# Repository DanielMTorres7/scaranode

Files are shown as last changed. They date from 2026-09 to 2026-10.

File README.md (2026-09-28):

# ScaraNode

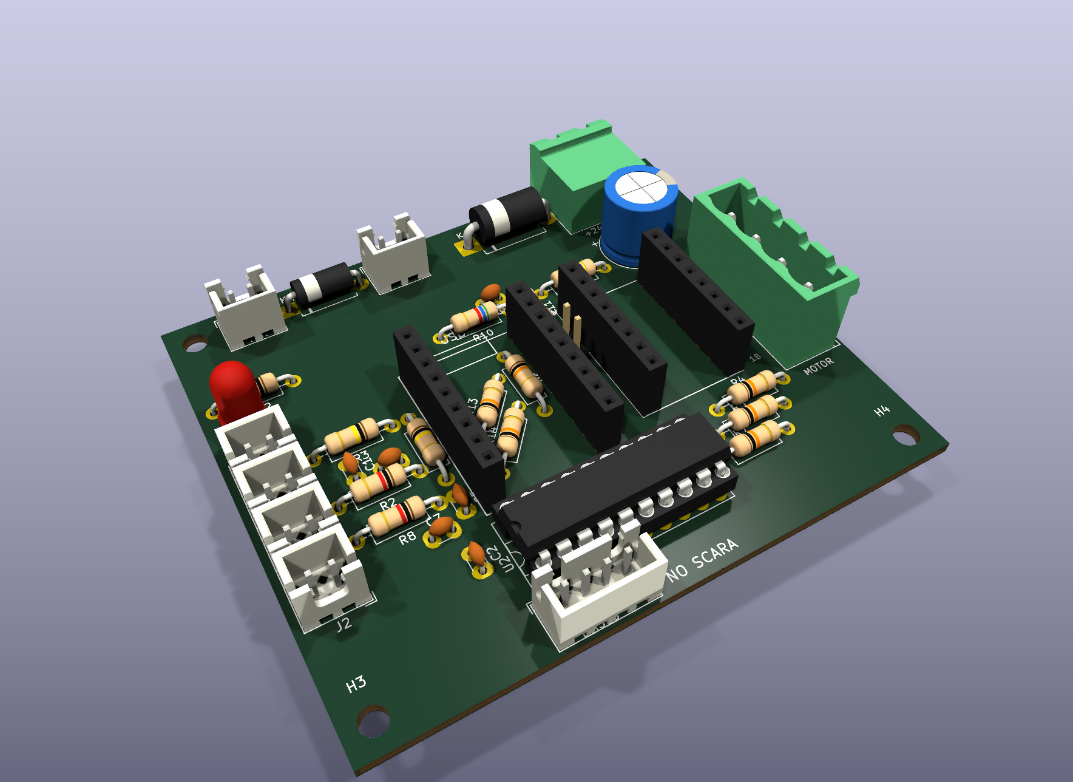
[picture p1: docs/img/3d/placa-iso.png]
ScaraNode


Placa de nó de motor **Klipper** para braço SCARA: **RP2040-Zero** + **TMC2209** (NEMA 17) e/ou driver
externo **DM556** (NEMA 23), cada um com STEP/DIR/enable próprios. Face única, 76 × 64 mm, feita para fresar em casa.

| Projetista | Revisão | Data | Estado |
|---|---|---|---|
| Daniel M. Torres | v18 | 27/09/2026 | Validada: 124 pinos, ERC e paridade 0, DRC de cobre sem erro, nenhuma curva de trilha de 90° |

📘 **[Manual completo](docs/README.md)** · 📄 **[PDF](docs/ScaraNode-Manual-v18.pdf)** ·
🧾 **[Lista de materiais](docs/02-lista-de-materiais.md)** · 🔧 **[Montagem](docs/04-montagem.md)** ·
⚙️ **[Klipper](docs/07-firmware-klipper.md)** ·
🎛️ **[Painel web](https://danielmtorres7.github.io/scaranode/)** ([como usar](firmware/painel/README.md))

## Estrutura

```
hardware/     placa e esquemático KiCad (ScaraNode.kicad_pro / .kicad_pcb / .kicad_sch + bibliotecas do projeto)
production/   arquivos para fabricar: gerber/, furação, BOM.csv
firmware/     configuração Klipper de referência; painel/ = painel web de bancada + firmware MicroPython
docs/         manual (Markdown + PDF), imagens, histórico de revisões
```

## Editar a placa

Abra `hardware/ScaraNode.kicad_pro` no **KiCad 10**: esquemático (`ScaraNode.kicad_sch`) e placa
(`ScaraNode.kicad_pcb`). As tabelas de biblioteca do projeto (`sym-lib-table`, `fp-lib-table`) apontam para as
bibliotecas padrão do KiCad 10 e para as próprias: `ScaraNode.kicad_sym` (RP2040-Zero, StepStick, 74ACT245, diodos)
e `ScaraNode.pretty` (soquetes do RP2040-Zero e do StepStick). Os comandos para
regerar Gerber e furação estão em [docs/03-fabricacao.md](docs/03-fabricacao.md#arquivos-de-produção).

Placa e esquemático foram gerados e conferidos por uma ferramenta própria em Python, que não faz parte deste
repositório (a paridade placa × esquemático é verificada pelo `kicad-cli`; a sincronização pela interface —
"Atualizar placa a partir do esquemático" — não foi testada). Os arquivos KiCad são completos e editáveis sem ela.

## Licença

Hardware sob **CERN-OHL-S-2.0** (ver [`LICENSE`](LICENSE)). Fotos de terceiros em `docs/img/componentes/`
mantêm as licenças listadas em [`CREDITOS.md`](docs/img/componentes/CREDITOS.md).

## Créditos

Modelos 3D das peças: bibliotecas oficiais do KiCad. Fotos de componentes: Wikimedia Commons, com
autores e licenças em [`docs/img/componentes/CREDITOS.md`](docs/img/componentes/CREDITOS.md).

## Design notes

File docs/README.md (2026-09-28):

# ScaraNode — Manual da Placa

<p align="center">ScaraNode em 3D</p>

Placa de nó de motor para um braço SCARA com **Klipper**: um **RP2040-Zero** por eixo, controlando um
**TMC2209** no soquete (NEMA 17) e/ou um **DM556** externo (NEMA 23), com canais independentes. Face única, feita para fresar em casa.

| | |
|---|---|
| **Projeto** | ScaraNode — nó de motor Klipper |
| **Projetista** | Daniel M. Torres |
| **Revisão** | v18 |
| **Data da revisão** | 27/09/2026 |
| **Placa** | 76 × 64 mm · FR-4 1,6 mm · cobre só na face de baixo (B.Cu) |
| **Ferramenta** | KiCad 10.0.6 · placa gerada por ferramenta própria em Python; fonte editável: `hardware/ScaraNode.kicad_pcb` |
| **Estado** | Validada: 124 pinos conferidos contra o esquemático (ERC 0, paridade 0), DRC de cobre sem erro, 0 ligações faltando e nenhuma curva de trilha de 90°; onde os courtyards se sobrepõem, corpos a ≥ 0,10 mm (menor 0,30 mm); vão mínimo 0,60 mm, anel mínimo 0,40 mm |

## Capítulos

| # | Capítulo | Conteúdo |
|---|---|---|
| 1 | [Visão geral](01-visao-geral.md) | O que a placa faz, especificações, blocos, diagrama |
| 2 | [Lista de materiais](02-lista-de-materiais.md) | Cada peça com foto, modelo 3D e onde encaixa |
| 3 | [Fabricação](03-fabricacao.md) | Regras de fresa, ferramentas, Gerber, espelhamento |
| 4 | [Montagem](04-montagem.md) | Ordem de solda passo a passo, polaridades, conferência |
| 5 | [Conectores, pinagem e jumpers](05-conectores-e-jumpers.md) | O que ligar em cada pino, jumper JU |
| 6 | [Circuitos e cálculos](06-circuitos.md) | Cada bloco explicado, com as contas |
| 7 | [Firmware Klipper](07-firmware-klipper.md) | Gravação do RP2040 e `printer.cfg` |
| 8 | [Primeira ligação e testes](08-testes.md) | Roteiro de ligação, diagnóstico, limites da placa |
| — | [Histórico de revisões](historico-de-revisoes.md) | Decisões de projeto, revisão por revisão |

**PDF:** [`ScaraNode-Manual-v18.pdf`](ScaraNode-Manual-v18.pdf), gerado destes mesmos arquivos. Esquemático: [`ScaraNode-Esquematico-v18.pdf`](ScaraNode-Esquematico-v18.pdf).

## Convenções deste manual

- **Vista de cima** = lado das peças, com o USB do RP2040-Zero para cima. Todas as imagens de montagem usam
  essa vista. A única vista espelhada é a do cobre, no capítulo de fabricação.
- Coordenadas em mm, com origem no canto superior esquerdo do RP2040-Zero (mesmo referencial da ferramenta de geração).
- Nomes de rede (`24V`, `VSENSE`, `STP`…) são os mesmos da placa no KiCad.
- ⚠️ marca o que queima peça ou inutiliza a placa se for feito errado.

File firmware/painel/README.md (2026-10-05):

# Painel web do ScaraNode

Painel de bancada para testar a placa sem Klipper: move o motor, configura o TMC2209 ou o DM556, lê fins de
curso, NTC e 24 V, e grava o próprio firmware na placa.

**Abrir:** <https://danielmtorres7.github.io/scaranode/> no **Chrome ou Edge** (computador). A página usa
Web Serial: a conexão vai direto do navegador para a placa ligada na USB do seu computador, sem passar
por servidor nenhum.

| Arquivo | O que é |
|---|---|
| `index.html` | o painel (arquivo único, sem dependências) |
| `no.py` | firmware MicroPython: servidor JSON pela USB, passos pela PIO + DMA |
| `main.py` | boot: deixa os drivers soltos e chama `no.rodar()` |
| `robo.html` | robô: várias placas ao mesmo tempo (J1, J2, Z), referência e desenho de SVG |

## Gravar o firmware

A placa precisa de **MicroPython** no RP2040-Zero (segure BOOT, ligue a USB e copie o `.uf2` do
[micropython.org](https://micropython.org/download/RPI_PICO/) para o drive `RPI-RP2`).
Depois, no painel, na aba **Firmware**:

1. confira a **revisão da placa** (só a v18): ela vai num `placa.py` (`REV = "v18"`) e decide os pinos;
2. clique em **Gravar firmware do site**.

O painel solta o motor, para o firmware e grava `main.py`, `no.py` e `placa.py` pelo raw REPL (como o
`mpremote`). Cada arquivo vai para um `.tmp`, é conferido (tamanho e SHA-256) e só então substitui o
antigo: se algo falhar no meio, a placa continua com o firmware anterior.

## Editar o firmware

Na aba **Firmware**, **Editar o firmware**: baixe `no.py`, `main.py` e `placa.py`, edite no seu editor e grave com
**Gravar arquivos do computador…** (um ou mais `.py`; só os escolhidos são trocados). Para voltar à versão
publicada, **Gravar firmware do site**. Para publicar a sua versão para todos, faça o commit aqui (veja abaixo).

## Pinos (v18)

| | v18 |
|---|---|
| STEP / DIR do TMC2209 | GP4 / GP5 |
| STEP / DIR do DM556 | GP6 / GP7 |
| UART do TMC2209 | GP2 |

As páginas não oferecem mais as placas até a v17 (STEP/DIR compartilhados, modo "Ambos"); o `no.py` ainda tem a pinagem delas.

Comuns: EN do TMC GP0, 24 V GP1, ENA do DM556 GP8, FIM1 GP27, FIM2 GP15, NTC GP29, LED GP16.
Revisão nova: uma linha na tabela `PLACAS` do `no.py` e uma opção no seletor do `index.html`.

## Robô (várias placas)

**Abrir:** <https://danielmtorres7.github.io/scaranode/robo.html> (ou o botão **Robô** no painel). Uma conexão
por placa: **Adicionar placa** para cada uma; na próxima vez o navegador reconecta sozinho.

- **Eixos:** cada eixo (J1, J2, Z) diz em que placa e em que driver está ligado, a redução (ou o avanço do fuso),
  o sentido, os limites, a velocidade e como é referenciado (manual ou por fim de curso). J1 e J2 precisam estar
  na mesma placa v18, um no TMC2209 e o outro no DM556: a placa entra no modo **dois**.
- **Tudo fica salvo na placa** (`config.json`, comando `salva`): driver, correntes, fins de curso e os eixos
  ligados nela; o comprimento do braço vai com o J1 e as alturas da caneta com o Z. A placa já liga
  configurada (motores soltos) e o painel lê tudo de volta ao conectar, em qualquer computador.
- **Firmware:** na aba **Placas**, cada placa mostra a versão dela e a do site; **Atualizar** grava a última
  versão com a revisão que a própria placa informa (v18). O `config.json` não é tocado.
- **Desenho:** formas prontas ou um arquivo SVG (linhas, curvas, retângulos, círculos; texto precisa virar
  curva), posição e tamanho na área de trabalho, velocidade. **Simular** mostra o movimento sem mexer nos
  motores; **Desenhar** manda a trajetória.

Como a trajetória anda: o painel faz a cinemática inversa e planeja a velocidade (reduz nos cantos e onde as
juntas ficariam rápidas demais), divide em segmentos de 10 ms e manda os passos de cada segmento para a placa
(`tjini`/`tj`). Na placa, cada canal tem a sua SM da PIO lendo um anel de 512 segmentos por DMA; as duas partem
no mesmo ciclo e o painel acerta os atrasos para os dois canais não se afastarem mais que ~1 µs. Se a USB
atrasar e os dados acabarem, a SM para no fim do que chegou e a posição continua exata.

O painel de uma placa troca o modo do driver para o que estiver escolhido nele: depois de usá-lo numa placa do
robô, reinicie a placa (ela volta ao que está no `config.json`).

## Publicar uma versão nova

Edite `no.py` (suba `FW = "painel 1.x"`) e dê push em `main`: o workflow `.github/workflows/painel.yml`
publica no GitHub Pages. Quem abrir o painel vê "diferente do site" ao conectar e grava com um clique.

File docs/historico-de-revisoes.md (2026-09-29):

# Histórico de revisões

Projetista: **Daniel M. Torres**.

| Rev. | Data | Resumo |
|---|---|---|
| v18 | 27/09/2026 | Um canal por driver: TMC2209 no GP4/GP5 e DM556 no GP6/GP7, independentes; UART do TMC2209 no pino 4 do soquete (GP2); sem o jumper ZM (MS1/MS2 fixos, endereço 3); segundo NTC (J8, GP26); segunda ventoinha (J9); conectores plugáveis 2EDG no J5/J6; furos M3 esquadrados; fusível de 2 A por placa na caixa central; nenhuma curva de trilha de 90° |
| v17 | 25/09/2026 | Esquemático KiCad publicado (ERC e paridade com a placa); 13 resistores iguais de 1/4 W; R13 e R14 inclinados a 50° com o GND do RP ligado direto ao plano; coluna da esquerda com folgas iguais; GND contínuo sem o jumper de fio JP1; faixas de cor nos renders |
| v16 | 25/09/2026 | Placa 76 × 64 mm com furos M3 alinhados + DXF mecânico; U2 em soquete DIP-20; borne do motor KF128 azul; NTC separado dos fins de curso; LED de 5 mm |
| v15 | 25/09/2026 | Conectores de sinal passam a JST XH 2,5 mm (as peças reais); 74ACT245 soldado direto; borne da 24 V verde e do motor azul |
| v14 | 25/09/2026 | ENA do DM556 no GP8 (J4 passa a 4 vias); pull-ups de 10k R13/R14 nos fins de curso. Manual e repositório publicados. |
| v13 | 25/09/2026 | Só duas brocas (1,0 e 1,6 mm) + M3 |
| v12 | 25/09/2026 | C10 = 470 µF 35 V; placa passa a 75,8 × 64 mm |
| v11 | 24/09/2026 | Jumper JU: UART do TMC2209 no GP5 |
| v10 | 24/09/2026 | LED D3 na borda; trilha de retorno de GND do borne |
| v9 | 24/09/2026 | Anel dos conectores KK corrigido (0,40 mm); primeiros Gerbers |
| v1–v8 | 24/09/2026 | Layout inicial, regras de fresa, pinagem do RP2040 |

## v18 — canais independentes, UART no pino 4 e trilhas sem curva de 90°

- **Um canal por driver.** Até a v17, o GP6/GP7 ia ao TMC2209 e ao 74ACT245 ao mesmo tempo: com os dois drivers
  ligados, os motores faziam o mesmo movimento. Agora cada driver tem STEP, DIR e enable próprios:

  | | STEP | DIR | Enable | UART |
  |---|---|---|---|---|
  | TMC2209 (soquete U4) | GP4 | GP5 | GP0 (ativo baixo) | GP2 (JU) |
  | DM556 (J4, via 74ACT245) | GP6 (`!`) | GP7 | GP8 (alto = habilitado) | — |

  Uma placa pode mover dois motores diferentes ao mesmo tempo. O DM556 fica com as trilhas da v17 até o 245. As do
  GP4/GP5 descem duas fileiras no canal entre o RP e o soquete do TMC.
- **UART no pino 4 do StepStick.** Nos módulos TMC2209 comuns (e no usado nos testes), o PDN_UART fica na
  posição do MS3 (pino 4), não no pino 5. O JU liga o GP2 ao pino 4, com o R7 (10k) como pull-up. O pino 5 fica
  livre. Módulos com a UART no pino 5 (Watterott SilentStepStick) deixam de servir.
- **Sem o jumper ZM.** Com a UART, o Klipper tira o micropasso do cfg (`mstep_reg_select`) e MS1/MS2 só dão o
  endereço; com um driver por RP, o endereço é fixo. R4 e R5 ficam: MS1 = MS2 = 1, endereço 3 (o mesmo do cfg) e
  1/16 em standalone. O jumper MS3 antigo, que aterraria a UART, sai junto.
  ⚠️ Placas até a v17: a UART vai ao pino 5. Com esse módulo, ligue um fio do JU.2 ao pino 4 e deixe o MS3 do ZM
  aberto.
- **Nenhuma curva de trilha de 90°.** Cada canto de 90° virou dois de 135°, com um trecho a 45° de 1 mm de perna.
  Junções em T continuam. A regra entrou na validação: a v17 tinha 18 cantos, a v18 tem 0.
- **Segundo NTC (J8, GP26).** Com dois motores na placa, cada um tem o seu termômetro. O pull-up (R15, 100k) fica
  deitado na vertical, ao lado do soquete do RP, do 3V3 ao GP26. O C1 e o C4 saíram dessa coluna e foram para o vão
  entre o R3 e o R2, e o C7 (100 nF) fica abaixo do R8. Os quatro conectores da esquerda (NTC1, FIM1, NTC2, FIM2)
  ficam a 6,05 mm uns dos outros, e a trilha de 5 V desceu 1,1 mm para o J2 caber. Com o GP26 ocupado, sobram GP3,
  GP14 e GP28: o ADXL345 (só SPI no Klipper) não cabe mais; use um acelerômetro I2C.
- **Fusível por placa, na caixa central.** Um TMC2209 pegou fogo a 1,7 A (acima dos 1,0–1,2 A que o StepStick
  aguenta), e o fusível único da máquina, dimensionado para tudo, não abriu. Agora cada placa tem o seu fusível de
  2 A, e cada DM556 o seu de 5 A, numa caixa de fusíveis de lâmina automotiva (32 V DC, fácil de achar). Ficou fora
  da placa: os DM556 também precisam de fusível e não passam por ela, e um porta-fusível de placa barato e fácil de
  achar não coube na faixa de 24 V com as duas brocas. Detalhes e contas no [capítulo 6](06-circuitos.md#fusíveis-fora-da-placa).
- **Segunda ventoinha (J9), sempre ligada**, entre o D2 e o D1: J7 no TMC2209, J9 no DM556 ou na caixa.
- **Conectores plugáveis 2EDG (5,08 mm)** no lugar dos bornes de parafuso: J5 (24 V) macho 90° 2EDGRC com o plugue
  entrando pela borda de cima; J6 (motor) macho vertical 2EDGVC, plugue por cima e fio para a direita. Plugue 2EDGK
  nos dois. O J6 desceu 1,6 mm (o macho é mais comprido e encostava no parafuso do H2).
- **Furos M3 esquadrados:** o H2 foi para o canto de cima (retângulo de 69 × 57 mm com os outros três). O J5 foi
  5,6 mm para a esquerda e o D1 4,5 mm; a 24 V passa a descer pelo R9 até o C10 e do C10 ao VM do TMC.
- Validado: 128 pinos, 0 violações de cobre, 0 ligações faltando, ERC e paridade 0.
- **Validada em hardware (29/09/2026)**, placa fresada na CNC, RP2040-Zero com MicroPython 1.29 e firmware do painel
  1.12: UART do TMC2209 pelo GP2 → pino 4 (endereço 3, versão 0x21), 24 V no GP1, NTC1 (GP29), NTC2 (GP26), FIM1 (GP27), FIM2 (GP15) e o canal do DM556
  (STEP GP6, DIR GP7, ENA GP8 pelo 74ACT245 até o J4) girando o motor. Na montagem, a perna 2 do 74ACT245 (saída
  PUL) sem contato deixava o DM556 só dar um tranco ao habilitar: confira as pernas do CI no soquete.

## v17 — esquemático e resistores iguais

- **Esquemático** em `hardware/ScaraNode.kicad_sch` e em [PDF](ScaraNode-Esquematico-v17.pdf): uma folha, blocos
  por função, rótulos na ponta dos pinos. ERC sem erro nem aviso; paridade placa × esquemático sem divergência.
  Símbolos próprios em `hardware/ScaraNode.kicad_sym`, footprints próprios em `hardware/ScaraNode.pretty`.
- Pinos livres ganham na placa a rede `unconnected-(…)` que o esquemático gera; o cobre não muda.
- **R13 e R14 passam a 1/4 W, furos a 10,16 mm** (antes 1/8 W a 7,62): os 13 resistores são iguais. Continuam
  embaixo do RP2040-Zero.
- Coluna da esquerda (XH, R2/R3/R8, C1/C4/C5, barra fêmea do RP) com folgas iguais entre corpos: ~0,9 mm do XH à
  perna do R e da perna do R ao capacitor (medidas com perna de 0,8 mm, acima da real), ~1,0 mm do capacitor à
  barra fêmea. O capacitor para no limite da isolação de 0,6 mm com as ilhas livres do RP.
- As exceções de courtyard deixam de ser uma lista fixa: onde os courtyards se sobrepõem ou os corpos ficam a menos
  de 2 mm, a folga real entre os corpos (desenho de fabricação, pernas pelo furo) tem que ser ≥ 0,10 mm. Menor
  folga: 0,30 mm (J7 × cabeça do M3 do H1). O DRC do KiCad continua marcando 13 sobreposições de courtyard como
  erro; são essas, conferidas pela folga real.
- **Sem jumper de fio**: o U2 (74ACT245), o C2 e a trilha de 5 V que chega a eles descem 1 mm; o J4 fica onde
  estava. O plano de GND passa a chegar à coluna da esquerda (NTC e fins de curso) entre o último pino do
  RP2040-Zero e a trilha de 5 V, e o JP1 (fio de GND por cima da trilha de 5 V) sai da placa, da lista de
  materiais e da montagem. O J4 fica a
  ~0,5 mm do soquete do U2; o U2 se afasta do RP (~1,7 mm).
- **R13 e R14 inclinados a 50°, paralelos**: a ilha do fim de curso fica na altura do GP27/GP15 (trilhas retas) e a
  ilha de 3V3 dos dois cai na mesma trilha de 3V3, que agora desce a ~9,4 mm da fileira esquerda do RP (antes
  descia a 3,2 mm). Com isso o **GND do RP2040-Zero liga direto ao plano de GND de cima** por um canal de
  ~6 mm. O R6 passa um pouco para a direita (1,3 mm) e o EN chega a ele em L, sem ilha de cobre solta a mais.
  Folgas: R13 × R14, R13 × R6 e R14 × R6 ~0,8 mm; R13/R14 a ~1,2 mm da barra fêmea; R6 a ~0,9 mm da barra da
  direita.
- Renders com as faixas de cor de cada resistor.
- Validado: 126 pinos, ERC 0, paridade 0, 0 violações de cobre, 0 ligações faltando. Furação: 118 × 1,0 ·
  8 × 1,6 · 4 × 3,2.

## v16 — dimensões redondas, soquete DIP e DXF

- Contorno passa de 75,8 × 64 para **76 × 64 mm** (borda direita +0,2 mm).
- Furos M3 a 3,5 mm das bordas: H1/H3/H4 num retângulo de 69 × 57 mm; H2 na coluna do H4, 18 mm abaixo da borda
  de cima. Antes: H1 e H3 desalinhados 0,2 mm, cotas quebradas.
- U2 com footprint de **soquete DIP-20** (mesmos furos, corpo maior). Exceção medida: o corpo do soquete termina
  a ~1 mm da perna do R7.
- `production/ScaraNode-mecanico.dxf`: contorno, furos e cotas.
- Coluna da esquerda reorganizada: **NTC (J3) sozinho em cima** e os **dois fins de curso (J1, J2) juntos**
  mais abaixo, com um vão de ~9 mm entre os grupos. O J2 fica no limite da trilha de 5 V (y = 41,2).
- **LED de 5 mm** (mesmo passo de 2,54 mm e furo de 1,0 mm do de 3 mm); o R12 subiu 1 mm para ele caber.
  Folgas medidas: LED a ~0,7 mm do J3; J1 a ~1,6 mm da perna do R8.
- Validado: 128 pinos, 0 violações de cobre, 0 ligações faltando.

## v15 — conectores JST XH

- J1, J2, J3, J4 e J7 trocam o footprint Molex KK (2,54 mm) pelo **JST XH** (B2B/B4B-XH-A, 2,5 mm), que é o
  conector usado de fato. As ilhas continuam ovais de 1,8 × 2,4 mm com furo de 1,0 mm.
- J4: as trilhas do 74ACT245 (passo 2,54) fazem um desvio curto até os pinos do XH (passo 2,5).
- O corpo do XH é mais largo que o do KK. Exceções de courtyard aceitas, com as medidas do F.Fab:
  J1/J2/J3 × R2/R3/R8 (plástico a ~0,2 mm da perna do resistor, sem cobre no meio) e J7 × H1/D2 (~1 mm da
  cabeça do M3, ~1,5 mm da perna do D2). Afastar a coluna para a esquerda violaria a isolação da trilha de 5 V.
- U2 soldado direto (sem soquete DIP). Borne J5 verde (24 V), J6 azul (motor).
- Validado: 128 pinos, 0 violações de cobre, 0 ligações faltando. Furação igual: 120 × 1,0 · 8 × 1,6 · 4 × 3,2.

## v14 — ENA do DM556 e pull-ups dos fins de curso

- **ENA:** GP8 → B3 do 74ACT245 (pino 16, antes em GND) → A3 (pino 4) → J4.4. O J4 passa a KF2510 de
  4 vias: 5V, PUL−, DIR−, ENA−, com o ENA+ do DM556 no 5 V como PUL+/DIR+. GP8 alto = motor habilitado
  (`enable_pin: gpio8`, sem `!`). Com o RP em reset ou em boot, o GP8 fica baixo e o DM556 fica
  desabilitado até o Klipper assumir.
- **Pull-ups de 10k** R13 (GP27/FIM1) e R14 (GP15/FIM2) do lado do RP, embaixo do módulo. São de 1/8 W
  (DIN0204, furos a 7,62 mm), porque o de 1/4 W encostava no soquete. O R14 fica inclinado 60°.
- Exceção de DRC aceita: o canto do courtyard do R14 invade ~0,2 mm o do soquete do RP. A ilha fica a
  0,68 mm do plástico.
- Validado: 128 pinos, 0 violações de cobre, 0 ligações faltando.

## v13 — só duas brocas

- Furos ≤ 1,2 mm viram 1,0 mm; entre 1,2 e 3,0 mm viram 1,6 mm; 3,2 mm (M3) fica. As ilhas cresceram onde
  foi preciso para manter o anel ≥ 0,4 mm.
- Pinos 1 e 19 do U2 com ligação sólida ao plano (não cabia o alívio térmico).

## v12 — C10 de 470 µF

- C10 = 470 µF 35 V (Ø10 mm, passo 5 mm), para absorver a energia de frenagem com o D1 em série.
  Com 470 µF, o VM sobe a ~27,4 V na frenagem estimada; com 100 µF chegava a ~30 V.
- A faixa de 24 V inteira subiu 4 mm para o capacitor caber; a placa passou a 75,8 × 64 mm.

## v11 — jumper de UART

- JU (1x2) entre o RP e o TMC: JU.2 ← GP5, JU.1 → pino 5 do StepStick (PDN_UART). Aberto = standalone.
- Sem resistor e sem pull-up: UART de 1 fio half-duplex.
- Os pinos 5–6 do soquete não ficam mais livres para o curto RST/SLP de A4988/DRV8825.

## v10 — LED na borda e retorno de GND

- D3 na borda esquerda, abaixo do R12.
- Trilha de GND de 2,5 mm do borne J5 até o C10 e dali ao pino 15 do TMC: caminho sólido para os pulsos do
  chopper, sem depender dos raios do alívio térmico.

## v9 — pronta para fresar

- Conectores KK com ilha oval de 1,8 × 2,4 mm e furo de 1,0 mm (anel de 0,40 mm; a biblioteca deixava
  0,28 mm).
- Menor vão entre redes: 0,601 mm. Menor anel: 0,40 mm.
- Primeiros Gerbers e a regra de espelhamento para fresar com o cobre para cima.

## Decisões de projeto que valem para todas as revisões

- **Fresa desconhecida → regras seguras:** isolação de 0,6 mm, sinal de 1,2 mm, ilhas generosas.
- **Ilhas de cobre soltas são mantidas:** sobra menos cobre para a fresa tirar.
- **Sem entrada de 5 V:** o USB é obrigatório para o Klipper e já alimenta a lógica.
- **Pino 6 (CLK) do StepStick livre:** aterrar sem medir o módulo pode danificar variantes que usam esse
  pino para outra coisa.
- **Sem homing sensorless:** o módulo usado não expõe o DIAG; o homing é por chave (J1/J2).
- **Fusível da 24 V:** fora da placa, na caixa central, mas **um por placa** (2 A) e um por DM556 (5 A) desde a v18.
- **LED:** R12 = 10k (~2,2 mA). Para mais brilho, R12 = 4k7 (~4,6 mA).

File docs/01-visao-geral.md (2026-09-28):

# 1. Visão geral

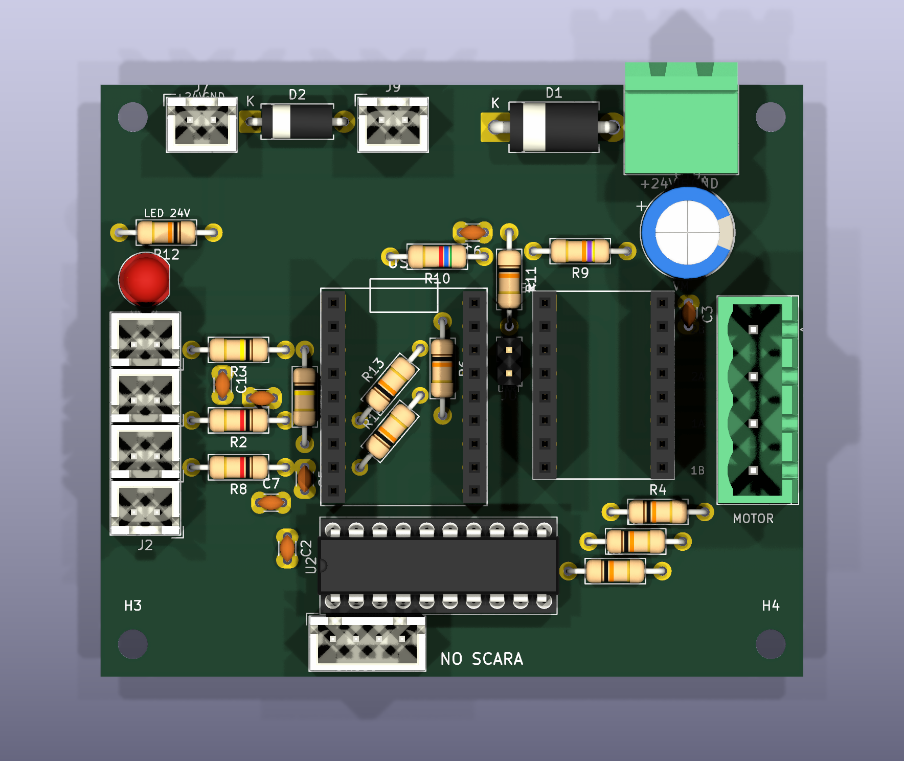
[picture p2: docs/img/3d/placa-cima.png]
Vista de cima em 3D


## O que a placa faz

Cada nó controla **um motor** do SCARA. O RP2040-Zero roda o firmware do Klipper e conversa com o host
(Raspberry Pi ou PC) pelo USB. O host coordena os quatro nós:

| Nó | Junta | Motor | Driver |
|---|---|---|---|
| J1 | ombro | NEMA 23 | DM556 externo, pelo conector J4 |
| J2 | cotovelo | NEMA 17 | TMC2209 no soquete U4 |
| Z | vertical | NEMA 23 | DM556 externo, pelo conector J4 |
| J3 | rotação da ferramenta | NEMA 17 | TMC2209 no soquete U4 |

É a **mesma placa nos quatro nós**. Só muda o que se monta nela:

| Variante | Monta | Fica vazio |
|---|---|---|
| **TMC2209** (J2, J3) | tudo, inclusive C3, R4–R7, JU, J6 e o módulo TMC2209 | J4 pode ficar sem cabo (o 74ACT245 não atrapalha) |
| **DM556** (J1, Z) | tudo menos o módulo TMC2209 | soquete U4 e conector J6 vazios; R4–R7 e JU opcionais |

## Especificações

| Item | Valor |
|---|---|
| Dimensões | 76 × 64 mm, 4 furos M3 (Ø3,2) a 3,5 mm das bordas; [desenho mecânico](03-fabricacao.md#desenho-mecânico) |
| Material | FR-4 1,6 mm, cobre só embaixo (B.Cu), fresada |
| Alimentação de potência | 24 V no conector plugável J5 (protegida contra inversão e surto) |
| Alimentação da lógica | 5 V e 3,3 V do USB do RP2040-Zero (ver [por que não há entrada 5 V](08-testes.md#o-que-a-placa-não-faz)) |
| Controle | Klipper, um RP2040-Zero por nó, USB para o host; até dois motores por nó (um no TMC2209, outro no DM556) |
| Driver interno | TMC2209 StepStick: 1,0–1,2 A RMS na prática |
| Driver externo | DM556 (ou similar, opto de ânodo comum): PUL, DIR e ENA em 5 V |
| Entradas | 2 NTC (um por motor), 2 fins de curso, monitor da 24 V |
| Saídas | motor (4 fios), ventoinha 24 V, PUL/DIR/ENA para driver externo, LED de 24 V |

## Diagrama de blocos

```mermaid
flowchart TB
    HOST["Host Klipper<br/>(Pi / PC)"] -- USB --> RP["U1 RP2040-Zero"]
    PSU["Fonte 24 V"] --> FUS["caixa de fusíveis<br/>2 A por placa"] --> J5["J5 conector 24 V"] --> D1["D1 1N5822<br/>anti-inversão"] --> BUS(("24 V"))
    BUS --> TVS["D2 P6KE30A + C10 470 µF"]
    BUS --> FAN["J7 ventoinha"]
    BUS --> LED["D3 LED + R12"]
    BUS --> DIV["R9/R10 divisor"] -- "VSENSE GP1" --> RP
    BUS -- VMOT --> TMC["U4 TMC2209"]
    RP -- "EN GP0 · STEP GP4 · DIR GP5" --> TMC
    RP -. "UART GP2 (JU)" .-> TMC
    TMC --> J6["J6 motor NEMA 17"]
    RP -- "STEP GP6 · DIR GP7 · ENA GP8" --> BUF["U2 74ACT245<br/>3,3 → 5 V"] --> J4["J4 → DM556"]
    NTC["J3 NTC1 · J8 NTC2"] -- "GP29 · GP26" --> RP
    SW["J1 / J2 fins de curso"] -- "GP27 · GP15" --> RP
```

## Blocos e peças

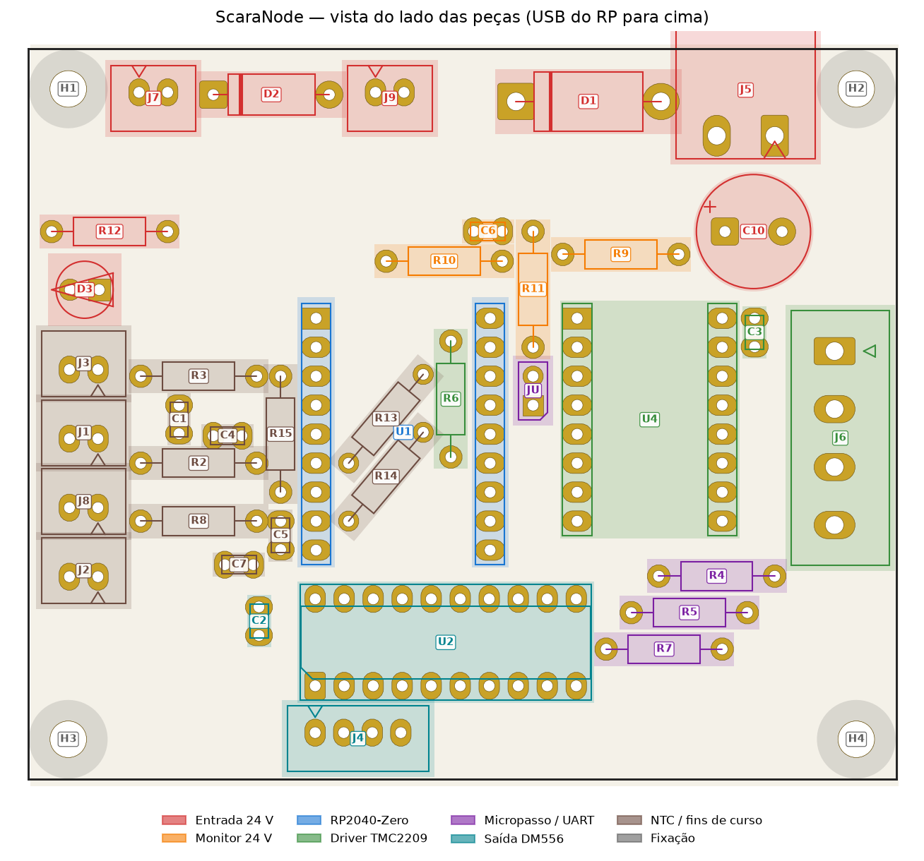
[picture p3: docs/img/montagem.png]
Peças coloridas por bloco


| Bloco | Peças | Função |
|---|---|---|
| Entrada 24 V | J5, D1, C10, D2, D3, R12, J7, J9 | Recebe a 24 V (fusível de 2 A por placa na caixa central). D1 protege contra inversão, D2 (TVS) contra surto, C10 guarda a energia de frenagem do motor, D3 acende com 24 V, J7 alimenta a ventoinha. |
| Monitor de 24 V | R9, R10, C6, R11 | Divisor 47k/5k6 leva 24 V a ~2,5 V no GP1. Se a potência cair, o Klipper faz M112. |
| Cérebro | U1 RP2040-Zero | Gera STEP/DIR, lê os sensores, fala com o host por USB. Fornece o 5 V (do USB) e o 3,3 V (regulador do módulo). |
| Driver TMC2209 | U4, R6, C3, J6 | Módulo StepStick. R6 deixa o driver desligado até o Klipper assumir. C3 desacopla o VMOT. J6 é o conector do motor. |
| Micropasso / UART | R4, R5, R7, JU | Pull-ups de 10k fixos em MS1/MS2 (R4, R5): endereço UART 3, ou 1/16 em standalone. JU fechado liga o GP2 ao PDN_UART (pino 4), que tem o R7 de pull-up. |
| Saída DM556 | U2, C2, J4 | Buffer de 3,3 para 5 V. As saídas afundam PUL−, DIR− e ENA− do DM556 (ânodo comum no 5 V). |
| NTC e fins de curso | J1, J2, J3, J8, R2, R3, R8, R13, R14, R15, C1, C4, C5, C7 | Dois NTC com pull-up de 100k no ADC. Chaves para GND com pull-up de 10k e filtro RC. |

Detalhes e contas no capítulo [6. Circuitos](06-circuitos.md).

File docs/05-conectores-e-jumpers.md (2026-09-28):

# 5. Conectores, pinagem e jumpers

Todas as posições abaixo são na **vista de cima** (lado das peças, USB do RP para cima).

## Pinagem do RP2040-Zero

Coluna esquerda, de cima para baixo: `5V, GND, 3V3, GP29, GP28, GP27, GP26, GP15, GP14`.
Coluna direita, de cima para baixo: `GP0 … GP8`. Os pinos castelados de baixo (GP9–GP13) não são usados.

| Pino | Rede | Função | No `printer.cfg` |
|---|---|---|---|
| 5V | `5V` | Vem do USB; alimenta o 74ACT245 e o PUL+/DIR+/ENA+ do DM556 | — |
| GND | `GND` | Terra comum (USB, 24 V, sensores) | — |
| 3V3 | `3V3` | Regulador do módulo; alimenta o VDD do TMC, os pull-ups e o NTC | — |
| GP0 | `EN` | Enable do TMC2209 (ativo baixo, pull-up R6) | `enable_pin: !gpio0` |
| GP1 | `VSENSE` | Monitor da 24 V (~2,5 V com 24 V) | `[gcode_button] pin: gpio1` |
| GP2 | `UART` | PDN_UART do TMC2209 (pino 4 do soquete), via jumper JU | `uart_pin: gpio2` |
| GP4 | `STP` | STEP do TMC2209 | `step_pin: gpio4` |
| GP5 | `DIR` | DIR do TMC2209 | `dir_pin: gpio5` |
| GP6 | `DM_STP` | PUL do DM556 via 74ACT245 | `step_pin: !gpio6` |
| GP7 | `DM_DIR` | DIR do DM556 via 74ACT245 | `dir_pin: gpio7` |
| GP8 | `ENA` | ENA do DM556 via 74ACT245 (alto = habilitado) | `enable_pin: gpio8` |
| GP15 | `SW2` | Fim de curso 2 (J2), pull-up 10k R14 | `endstop_pin: !gpio15` (NA) |
| GP27 | `SW1` | Fim de curso 1 (J1), pull-up 10k R13 | `endstop_pin: !gpio27` (NA) |
| GP26 | `NTC2` | ADC0, NTC2 (J8) com pull-up de 100k (R15) | `sensor_pin: gpio26` |
| GP29 | `NTC` | ADC3, NTC1 (J3) com pull-up de 100k (R3) | `sensor_pin: gpio29` |
| GP3, GP14, GP28 | livres | Sem trilha; acelerômetro I2C por fio (ver capítulo 6) | `i2c_software_*` |

**Dois canais independentes (v18):** o TMC2209 (GP4/GP5/GP0) e o DM556 (GP6/GP7/GP8) têm STEP, DIR e enable
próprios. Uma placa pode mover dois motores diferentes ao mesmo tempo, um em cada driver. Até a v17, o STEP e o DIR
iam juntos para os dois.

## Conectores

| Conector | Pino (vista de cima) | Liga em | Observação |
|---|---|---|---|
| **J5** 24 V (2EDG 90°, plugue pela borda de cima) | esquerda: **+24 V** | +24 V da fonte, por um fusível de 2 A **só desta placa** (ver [capítulo 6](06-circuitos.md#fusíveis-fora-da-placa)) | Passa pelo D1; invertido, nada liga |
| | direita: **GND** | 0 V da fonte | Mesmo GND do USB: fonte e host no mesmo terra |
| **J6** MOTOR (2EDG vertical, plugue por cima, fio para a direita) | de cima para baixo: **2B, 2A, 1A, 1B** | bobinas do NEMA 17 | Os dois de cima são uma bobina, os dois de baixo a outra. Trocar um par inverte o sentido (ou use `!` no `dir_pin`). |
| **J4** DM556 | 1 (esquerda): **5V** | PUL+, DIR+ e ENA+ do DM556 (juntos) | Ânodo comum. Sem resistor: o DM556 já limita para 5 V. |
| | 2: **PUL−** | PUL− do DM556 | Saída do 74ACT245 |
| | 3: **DIR−** | DIR− do DM556 | |
| | 4 (direita): **ENA−** | ENA− do DM556 | GP8 baixo (RP em reset) = motor desabilitado |
| **J3** NTC1 | direita: sinal · esquerda: GND | NTC 100k encostado no motor do TMC2209 | Sem polaridade |
| **J8** NTC2 | direita: sinal · esquerda: GND | NTC 100k encostado no motor do DM556 | Só com dois motores na placa |
| **J1 / J2** FIM | direita: sinal · esquerda: GND | chave fim de curso | Fecha para GND. NA ou NF: ajuste com `!` no cfg |
| **J7** FAN | esquerda: +24 V · direita: GND | ventoinha 24 V do TMC2209 | Sempre ligada |
| **J9** FAN2 | esquerda: +24 V · direita: GND | ventoinha 24 V do DM556 ou da caixa | Sempre ligada |
| **USB-C** | — | host (Pi/PC) | Um cabo por nó. Identifique cada nó por `/dev/serial/by-id/` |

<table><tr>
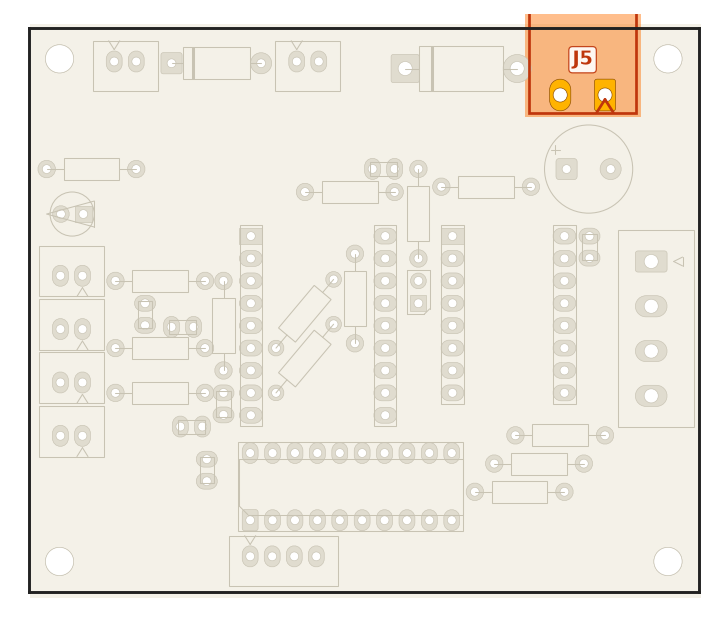
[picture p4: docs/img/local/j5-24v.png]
<td align="center"><br><sub>J5</sub></td>
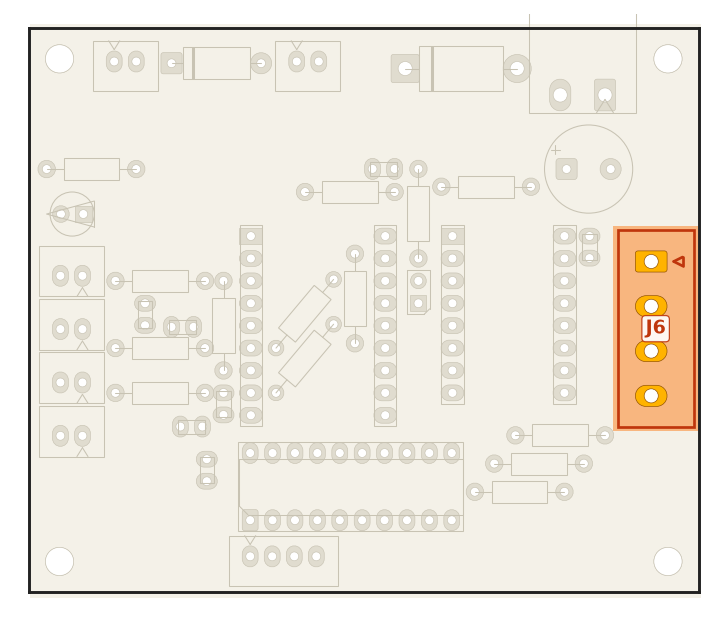
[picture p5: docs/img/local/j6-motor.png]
<td align="center"><br><sub>J6</sub></td>
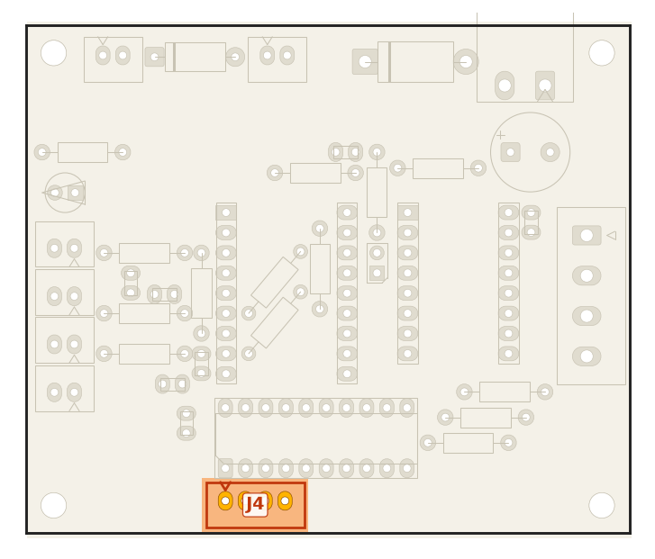
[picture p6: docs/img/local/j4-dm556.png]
<td align="center"><br><sub>J4</sub></td>
</tr><tr>
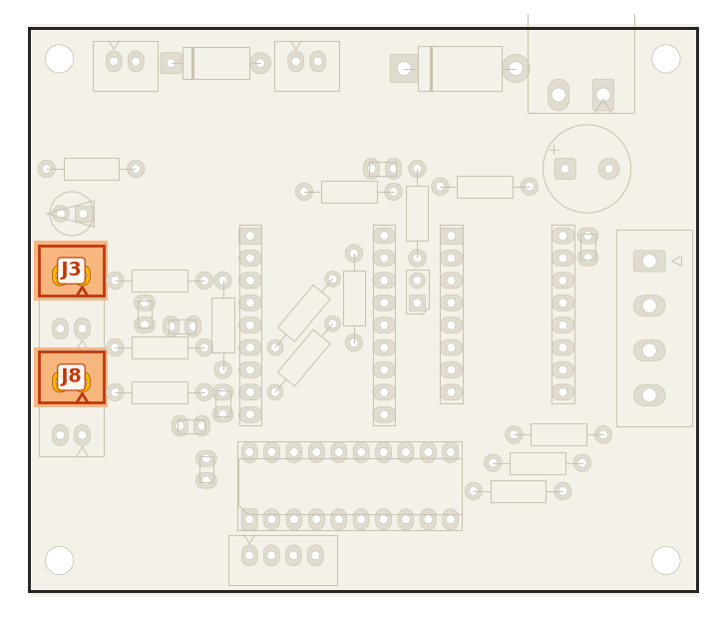
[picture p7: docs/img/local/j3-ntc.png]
<td align="center"><br><sub>J3</sub></td>
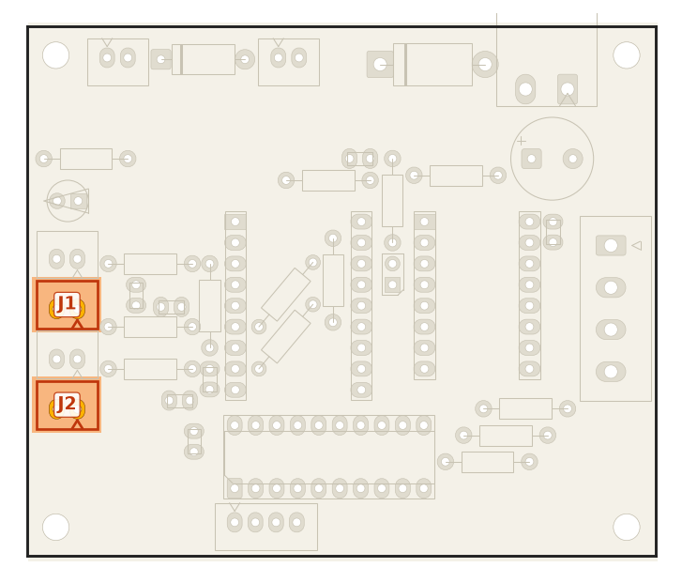
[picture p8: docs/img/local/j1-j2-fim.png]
<td align="center"><br><sub>J1 / J2</sub></td>
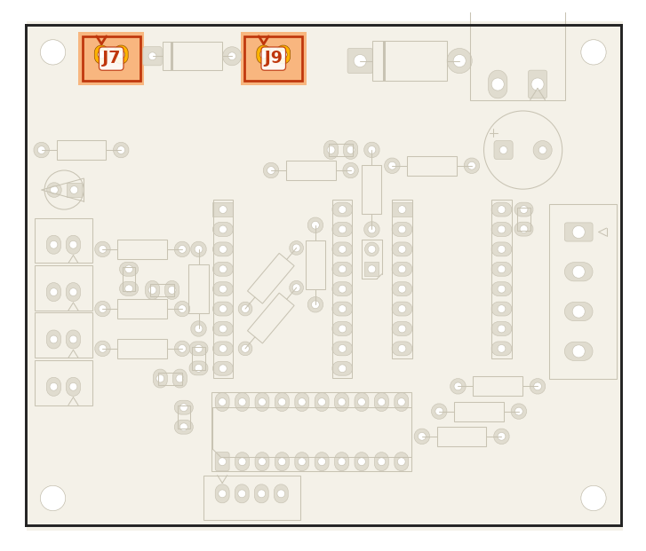
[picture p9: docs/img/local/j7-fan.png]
<td align="center"><br><sub>J7</sub></td>
</tr></table>

## Pinagem do soquete StepStick (U4)

| Pino | Função | Liga em | | Pino | Função | Liga em |
|---|---|---|---|---|---|---|
| 1 | EN | GP0 + R6 (pull-up) | | 16 | VMOT | 24 V (após D1) + C3 |
| 2 | MS1 | R4 (pull-up) | | 15 | GND | GND de potência |
| 3 | MS2 | R5 (pull-up) | | 14 | 2B | J6 |
| 4 | PDN_UART | JU → GP2, pull-up R7 | | 13 | 2A | J6 |
| 5 | — | **livre** | | 12 | 1A | J6 |
| 6 | CLK | **livre** (clock interno) | | 11 | 1B | J6 |
| 7 | STEP | GP4 | | 10 | VDD | 3V3 |
| 8 | DIR | GP5 | | 9 | GND | GND |

O pino 6 fica livre de propósito: aterrar sem medir pode danificar módulos que usam esse pino para outra
coisa. A4988 e DRV8825 só funcionam com o curto RST–SLP feito no próprio módulo (os pinos 5 e 6 da placa
não estão mais livres para isso).

## Jumpers

### MS1 e MS2 fixos (sem jumper desde a v18)

MS1 e MS2 ficam em 3,3 V pelos pull-ups R4 e R5. Até a v17 havia o jumper ZM para aterrá-los; ele saiu porque:

- **Com a UART** (o uso normal), o Klipper tira o micropasso dos pinos (`mstep_reg_select`) e usa o `microsteps` do
  cfg. MS1 e MS2 só dão o endereço da UART: os dois em 1 = **endereço 3** (`uart_address: 3`). Com um driver por
  RP, o endereço só precisa bater com o cfg.
- **Em standalone** (JU aberto), o TMC2209 fica em **1/16** (`microsteps: 16`).

**Pino 4 (posição do MS3):** nos módulos TMC2209 comuns, é o PDN_UART. Na v18 ele vai ao JU e tem o R7 (10k) como
pull-up. Até a v17 a UART ia ao pino 5, que no módulo usado não é a UART. Módulos com a UART no pino 5 (ex.:
Watterott SilentStepStick, que tem o SPREAD no pino 4) não servem nesta placa.

### JU — UART do TMC2209

- **Aberto:** driver em standalone. Corrente pelo trimpot, micropasso fixo em 1/16.
- **Fechado:** GP2 ligado ao PDN_UART (pino 4 do StepStick). Com a seção `[tmc2209]` no cfg, o trimpot
  é ignorado, o micropasso vem do cfg, e MS1/MS2 (fixos em 1) dão o endereço 3. Sem a seção no cfg, o driver
  continua em standalone mesmo com o JU fechado.
- UART de 1 fio (half-duplex), sem resistor em série: o Klipper alterna a direção do GP2. O R7 só segura o nível
  alto com o JU aberto.

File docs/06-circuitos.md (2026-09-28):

# 6. Circuitos e cálculos

O esquema completo está em `hardware/ScaraNode.kicad_sch` (KiCad 10) e em
[PDF, folha A3](ScaraNode-Esquematico-v18.pdf). Ele é desenhado por blocos, com rótulos na ponta de cada pino no
lugar de fios: pinos com o mesmo rótulo estão ligados.

<p align="center">Esquemático da ScaraNode</p>

Na v18 a placa confere com o esquemático: **124 pinos**, ERC sem erro nem aviso e paridade placa × esquemático
sem divergência (valor, footprint e rede de cada pino). Esquemático e conferência da placa saem da mesma descrição
do circuito: o ERC e a paridade conferem tipos de pino e a placa, não a concepção do circuito. Os trechos abaixo
seguem esse esquema.

## Entrada 24 V

```
J5 +24V ──►|── D1 1N5822 ──┬──────────┬──────────┬───────────┬─────────┬──► VMOT (U4.16)
            (anti-inversão) │          │          │           │         │
                          C10 470µF  D2 P6KE30A  J7/J9 FAN  R12 10k   R9 47k ─► monitor
                            │          │ (TVS)    │           │
J5 GND ─────────────────────┴──────────┴──────────┴──── D3 LED ┘
```

O +24 V desce pelo R9 até o C10 e só então vai ao VM do TMC (v18): o C10 fica no caminho do driver. O retorno
de GND do conector vai por uma trilha própria de 2,5 mm até o C10, e dali ao pino 15 do TMC. É o
caminho dos pulsos do chopper (até ~1 A), que não deve depender dos raios finos do alívio térmico do plano.

| Grandeza | Valor | Comentário |
|---|---|---|
| VM no TMC | 23,6 V | 24 V menos ~0,45 V do D1. O TMC2209 aceita de 4,75 a 29 V. |
| Frenagem | ~0,04 J (estimativa: J2, 24:1, 250 mm/s) | O D1 impede a energia de voltar para a fonte. Com 470 µF, o VM sobe a ~27,4 V; com 100 µF chegava a ~30 V. |
| TVS P6KE30A | trabalha até 25,6 V, conduz a partir de 28,5 V | Segura surtos; não é proteção fina para o driver |
| LED | (23,6 − 2) / 10k ≈ 2,2 mA | Visível. R12 = 4k7 dá ~4,6 mA |
| Ventoinhas (J7, J9) | 24 V direto, sempre ligadas | J7 no TMC2209, J9 no DM556 ou na caixa. Brushless não precisa de diodo. Sempre ligadas de propósito: uma ventoinha controlada por firmware pode ficar parada com o driver trabalhando |

## Fusíveis (fora da placa)

A placa não tem fusível: a proteção fica numa **caixa de fusíveis de lâmina automotiva** (6 ou 8 vias, de
autopeças), com **um fusível por circuito**. Até a v17 havia um fusível só para a máquina toda. Como ele é
dimensionado para a soma de tudo, inclusive os DM556, não abriu quando um TMC2209 entrou em curto e pegou fogo
(27/09/2026).

| Circuito | Fusível de lâmina (padrão ATO ou mini, 32 V DC) |
|---|---|
| Cada ScaraNode (TMC2209 + ventoinhas J7/J9) | **2 A** |
| Cada DM556 com NEMA 23 a 4,2 A | **5 A** |

- **Um fio por circuito, saindo da caixa.** Duas placas no mesmo fusível voltam ao problema original.
- **Por que 2 A:** pela placa passam só o TMC2209 e as ventoinhas. O driver converte 24 V com pouca corrente em
  poucos volts com mais corrente na bobina, então a fonte fornece só a potência gasta: bobinas (~4 W a 1,2 A),
  perdas do driver (~1 W), trabalho mecânico (até ~9 W) e ventoinhas (~7 W) dão ~0,9 A no pior caso e ~0,5 A
  parado. O fusível trabalha abaixo de 75% do valor e abre em milissegundos num curto (dezenas de ampères).
- **Por que o DM556 puxa menos que 4,2 A da fonte:** pelo mesmo motivo; 5 A é folga para as acelerações.
- **Tensão do fusível:** pelo menos **32 V DC**. É o padrão dos fusíveis de lâmina. Em DC a corrente não passa por
  zero e o fusível precisa apagar o arco sozinho; um fusível marcado só "250 V AC" não garante isso.
- **Pico ao ligar:** o C10 (470 µF) carrega com um pico de milissegundos (~0,5 A²s), bem abaixo do que funde um
  fusível de lâmina de 2 A.
- **Para conferir o consumo real:** multímetro em série no +24 V de uma placa (escala de 10 A DC), com a máquina no
  movimento mais pesado. Se passar de 1,5 A, suba para 3 A.
- **Fusível aberto:** procure o curto antes de trocar (driver, TVS D2, C10, motor).

## Monitor da 24 V

```
24V ── R9 47k ──┬── R11 10k ── GP1 (VSENSE)
                │
              R10 5k6   C6 100nF
                │         │
               GND       GND
```

- 23,6 × 5,6 / 52,6 = **2,51 V** no nó VSN com 24 V; 2,76 V com 26,4 V, ainda abaixo de 3,3 V.
- R11 limita a corrente pelo diodo interno do GP1 quando o RP está desligado e a 24 V presente.
- Abaixo do limiar de nível alto do RP2040, o botão "solta" e o Klipper executa o `release_gcode` (M112).

## Driver TMC2209

- VDD do módulo em 3,3 V (VCC_IO). **EN com pull-up de 10k (R6):** sem firmware rodando, o driver fica
  desligado.
- STEP e DIR chegam direto do RP (GP4, GP5), separados dos do DM556.
- MS1/MS2 fixos em 1 pelos pull-ups de 10k (R4, R5): endereço UART 3; em standalone, 1/16.
- Pino 4 (PDN_UART) chega ao GP2 pelo JU, com pull-up de 10k (R7). Pinos 5 e 6 (CLK) ficam abertos = clock
  interno.
- Módulo com RSENSE de 0,11 Ω: no cfg, `sense_resistor: 0.110`.
- **Corrente prática em StepStick: 1,0 a 1,2 A RMS, com ventoinha.** Acima disso o driver desarma por
  temperatura. Para 1,7 A, use driver externo pelo J4.

## Saída para driver externo (74ACT245)

```
            U2 74ACT245 (modo B→A: DIR=GND, OE#=GND, VCC=5V)
GP6 DM_STP ─► B1 (18) ──► A1 (2) ─► J4.2 PUL−
GP7 DM_DIR ─► B2 (17) ──► A2 (3) ─► J4.3 DIR−
GP8 ENA    ─► B3 (16) ──► A3 (4) ─► J4.4 ENA−          J4.1 = 5V ─► PUL+ / DIR+ / ENA+
              B4–B8 (15–11) = GND
```

- Entradas TTL do ACT (nível alto ≥ 2,0 V) aceitam os 3,3 V do RP.
- Com PUL+/DIR+/ENA+ em 5 V, a saída em nível baixo acende o opto do DM556 (~14 mA; o 245 aguenta
  24 mA por saída).
- Pulso de STEP ativo baixo: `step_pin: !gpio6` e `step_pulse_duration: 0.000005` (o DM556 pede 2,5 µs).
- **ENA:** GP8 alto → A3 alto → opto apagado → motor **habilitado** (`enable_pin: gpio8`, sem `!`). Com o RP em
  reset ou em boot, o GP8 fica baixo e o DM556 fica desabilitado até o Klipper assumir.
- O DM556 é opticamente isolado, então não se forma laço de terra.

## NTC

```
3V3 ── R3 100k ──┬── GP29 (ADC3)        NTC2: R15, C7, J8, GP26 (ADC0)
                 ├── C1 100nF ── GND
                 └── J3 ── NTC 100k ── GND
```

100k a 25 °C com pull-up de 100k dá 1,65 V; a 70 °C (~17,6k) dá ~0,49 V. O C1 filtra o ruído do cabo.
Desde a v18 há duas entradas iguais: com dois motores na placa, uma em cada motor. O NTC fica no motor, não no
driver: o TMC2209 se desliga sozinho por temperatura (e o Klipper avisa), e o DM556 tem as próprias proteções.

## Fins de curso

```
3V3 ── R13 10k ──┬── GP27        (FIM2: R14, R8, C5, GP15)
                 ├── C4 10nF ── GND
                 └── R2 1k ── J1 ── chave ── GND
```

Pull-up externo de 10k no lado do RP, 1k em série e 10 nF (RC de ~10 µs). Com a chave fechada, o pino fica
em 3,3 × 1/11 ≈ **0,30 V**. Por causa dos pull-ups externos (v14), o `^` no cfg é opcional.

## Pinos livres do RP2040

GP3, GP14 e GP28 não têm trilha. Com o GP26 no NTC2 (v18), sobram GP3, GP14 e GP28. O ADXL345 no Klipper só funciona por SPI (4 fios) e não cabe; use um acelerômetro I2C (MPU-6050/9250 ou LIS2DW, 2 fios, `i2c_software_*` no GP3/GP14) ou um acelerômetro USB à parte. Há um exemplo comentado em
`firmware/klipper/scaranode.cfg`.

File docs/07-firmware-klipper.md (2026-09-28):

# 7. Firmware Klipper

Cada nó é um micro-controlador (`[mcu <nome>]`) do Klipper. O host fala com os quatro pelo USB, e os
pinos de cada nó levam o prefixo do nome (`j2:gpio4`).

Desde a v18 os dois drivers têm pinos próprios: um nó pode mover um motor no TMC2209 **e** outro no DM556 ao
mesmo tempo. Nesse caso, use o FIM1 (`gpio27`) para o eixo do TMC e o FIM2 (`gpio15`) para o do DM556: cada
chave fica no mesmo MCU que o seu motor, o que é o melhor para o homing.

## Gravar o Klipper no RP2040-Zero

No host, na pasta do Klipper:

```sh
make menuconfig
#   Micro-controller Architecture: Raspberry Pi RP2040/RP235x
#   Processor model: rp2040 · interface de comunicação: USB (padrão)
make
```

Primeira gravação: segure o botão **BOOT** do RP2040-Zero e conecte o USB. Ele aparece como um disco
(`RPI-RP2`): copie o `out/klipper.uf2` para lá, ou grave pelo host:

```sh
sudo service klipper stop
make flash FLASH_DEVICE=2e8a:0003   # RP2040 em modo BOOT (Klipper atual)
sudo service klipper start
```

Nas atualizações seguintes, com o nó já rodando o Klipper, `FLASH_DEVICE` pode ser o caminho
`/dev/serial/by-id/...` do nó.

Grave **um nó por vez** e anote o serial de cada um:

```sh
ls /dev/serial/by-id/
# usb-Klipper_rp2040_E6625C05E7xxxxxx-if00   ← cole no [mcu j2] serial:
```

Dica: etiquete cada placa (J1, J2, Z, J3) junto com o final do serial.

## Configuração

Referência completa, comentada: [`firmware/klipper/scaranode.cfg`](../firmware/klipper/scaranode.cfg).
Ela saiu da placa (pinagem conferida pino a pino), não do `printer.cfg` da máquina. O que depende da
mecânica e da cinemática SCARA está marcado com `# AJUSTAR`.

### Nó com TMC2209 (NEMA 17)

```ini
[mcu j2]
serial: /dev/serial/by-id/usb-Klipper_rp2040_XXXX-if00

[stepper_j2]
step_pin: j2:gpio4
dir_pin: j2:gpio5
enable_pin: !j2:gpio0          # EN ativo baixo
microsteps: 16                 # com UART vem daqui; em standalone é fixo em 1/16
gear_ratio: 6:1, 4:1
endstop_pin: !j2:gpio27        # chave NA para GND

[temperature_sensor motor_j2]
sensor_type: Generic 3950
sensor_pin: j2:gpio29
pullup_resistor: 100000
max_temp: 70

[gcode_button vm_sense_j2]
pin: j2:gpio1
press_gcode:
  G4 P0
release_gcode:
  M112
```

Com o **JU fechado** (recomendado), acrescente:

```ini
[tmc2209 stepper_j2]
uart_pin: j2:gpio2              # PDN_UART no pino 4 do soquete (v18)
uart_address: 3                # MS1 e MS2 fixos em 1 (R4/R5)
run_current: 1.0               # MÁXIMO 1,2 no StepStick
sense_resistor: 0.110
stealthchop_threshold: 0
```

### ⚠️ Para não queimar o driver

Um TMC2209 pegou fogo depois de rodar muito tempo a 1,7 A (27/09/2026). O que evita isso:

1. **`run_current` no máximo 1,0–1,2 A** no TMC2209. O StepStick não dissipa mais que isso, mesmo com ventoinha.
   O Klipper não impede um valor maior: o limite é seu. Motor que precisa de mais corrente vai no DM556.
2. **Use a UART.** Só com ela o Klipper lê os avisos de temperatura do TMC2209 (pré-aviso a ~120 °C, desligamento a
   ~143 °C) e para a máquina com erro. Em standalone, ninguém vigia o driver.
3. **Nunca ligue nem desligue o cabo do motor com a 24 V ligada.** A bobina gera um pico que mata o driver na hora,
   e nenhum componente da placa impede.
4. **Ponteira (terminal tubular) nos fios** dos plugues do motor (J6) e da 24 V (J5), bem apertados, e o plugue
   encaixado até o fim. Contato frouxo faz faísca.
5. **Fusível de 2 A só para esta placa** na caixa de fusíveis ([capítulo 6](06-circuitos.md#fusíveis-fora-da-placa)).
6. **Ventoinha no J7** sempre ligada, soprando o módulo.

### Nó com DM556 (NEMA 23)

```ini
[stepper_j1]
step_pin: !j1:gpio6            # pulso ativo baixo (ânodo comum)
dir_pin: j1:gpio7
enable_pin: j1:gpio8           # alto = habilitado, SEM !
step_pulse_duration: 0.000005
```

O `microsteps` do Klipper tem que ser igual ao configurado nas chaves do DM556.

## Tabela rápida de sinais

| Função | TMC2209 | DM556 |
|---|---|---|
| STEP | `gpio4` | `!gpio6` |
| DIR | `gpio5` | `gpio7` |
| Enable | `!gpio0` | `gpio8` |
| UART | `gpio2` (JU fechado) | — |
| NTC | `gpio29` (J3), pull-up 100000 | `gpio26` (J8) com dois motores na placa; `gpio29` com um |
| Fim de curso 1 / 2 | `!gpio27` / `!gpio15` (NA) | idem |
| Monitor 24 V | `gpio1` | idem |

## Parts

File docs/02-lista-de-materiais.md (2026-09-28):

# 2. Lista de materiais

A lista de compras oficial é [`production/BOM.csv`](../production/BOM.csv), gerada direto da placa. Este
capítulo mostra **cada item** com uma imagem de referência, o modelo 3D usado no KiCad e o lugar exato na placa
(vista de cima, peça em laranja).

> Foto só aparece quando mostra a peça certa. Onde não há foto livre da peça exata, a referência é o modelo 3D
> ou um desenho gerado da própria placa (faixas de cor dos resistores, pinagem dos módulos). Créditos das fotos:
> [`img/componentes/CREDITOS.md`](img/componentes/CREDITOS.md).

## Resumo

| Qtd | Item | Referências |
|---|---|---|
| 1 | Waveshare RP2040-Zero | U1 |
| 1 | Módulo TMC2209 StepStick (só nós NEMA 17) | U4 |
| 1 | SN74ACT245N DIP-20 | U2 |
| 1 | Soquete DIP-20 300 mil | U2 |
| 1 | Schottky 1N5822 | D1 |
| 1 | TVS P6KE30A | D2 |
| 1 | LED 5 mm | D3 |
| 1 | Eletrolítico 470 µF 35 V | C10 |
| 5 | Cerâmico 100 nF (104) | C1 C2 C3 C6 C7 |
| 2 | Cerâmico 10 nF (103) | C4 C5 |
| 8 | Resistor 10k 1/4 W | R4 R5 R6 R7 R11 R12 R13 R14 |
| 2 | Resistor 1k 1/4 W | R2 R8 |
| 2 | Resistor 100k 1/4 W | R3 R15 |
| 1 | Resistor 47k 1/4 W | R9 |
| 1 | Resistor 5k6 1/4 W | R10 |
| 1 | Conector 2EDG 2 vias 5,08 mm (macho 90° 2EDGRC + plugue 2EDGK) | J5 |
| 1 | Conector 2EDG 4 vias 5,08 mm (macho vertical 2EDGVC + plugue 2EDGK) | J6 |
| 1 | JST XH 4 vias | J4 |
| 6 | JST XH 2 vias | J1 J2 J3 J7 J8 J9 |
| 1 | Barra macho 1x2 + 1 jumper | JU |
| 2 | Barra fêmea 1x9 | soquete do U1 |
| 2 | Barra fêmea 1x8 | soquete do U4 |
| 4 | Parafuso M3 + espaçador | H1–H4 |

**Fora da placa:** um ou dois NTC 100k B3950 com fio (J3, J8), duas chaves fim de curso NA ou NF (J1/J2), ventoinha 24 V (J7),
cabo USB-C, fonte de 24 V, **fusível de lâmina de 2 A só para esta placa** na caixa de fusíveis central
([capítulo 6](06-circuitos.md#fusíveis-fora-da-placa)). Nos nós J1 e Z: driver DM556 e motor NEMA 23.

<table><tr>
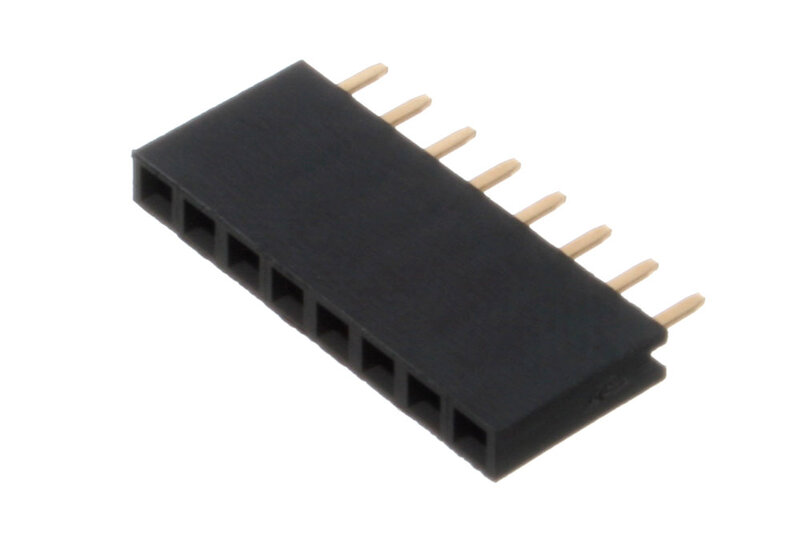
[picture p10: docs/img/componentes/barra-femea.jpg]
<td align="center"><br><sub>Barra fêmea (soquetes do RP e do TMC)</sub></td>
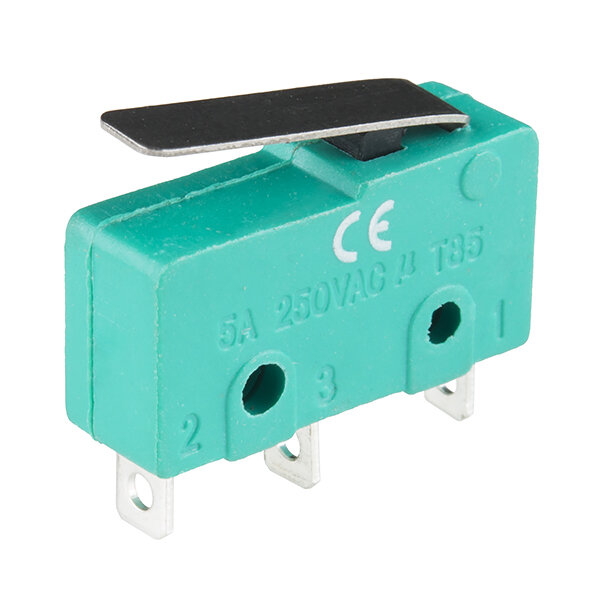
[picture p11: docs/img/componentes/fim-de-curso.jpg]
<td align="center"><br><sub>Chave fim de curso</sub></td>
</tr></table>

## Item por item

<div class="card" markdown="1">

### RP2040-Zero (U1)

| Qtd | Referências | Valor | Comprar |
|---|---|---|---|
| 1 | U1 | RP2040-Zero | Waveshare RP2040-Zero + 2 barras fêmea 1x9 2,54 mm |

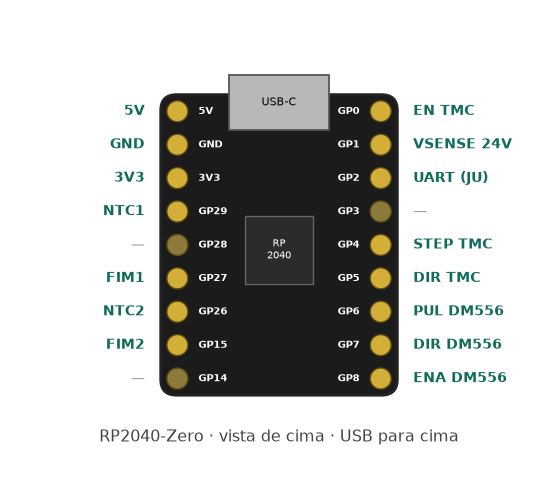
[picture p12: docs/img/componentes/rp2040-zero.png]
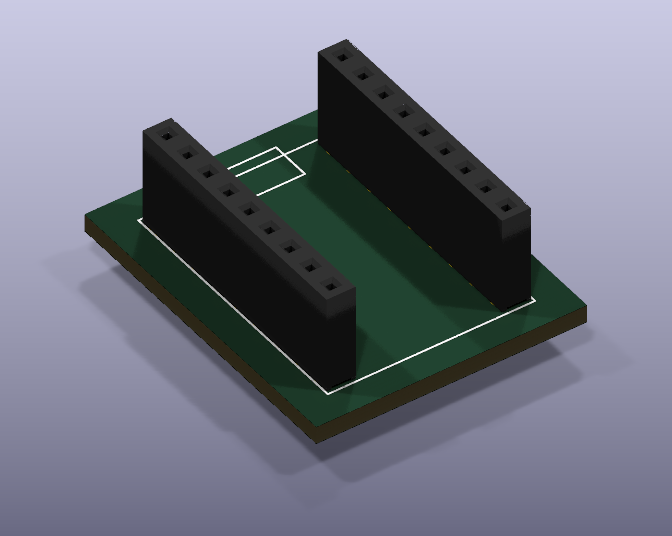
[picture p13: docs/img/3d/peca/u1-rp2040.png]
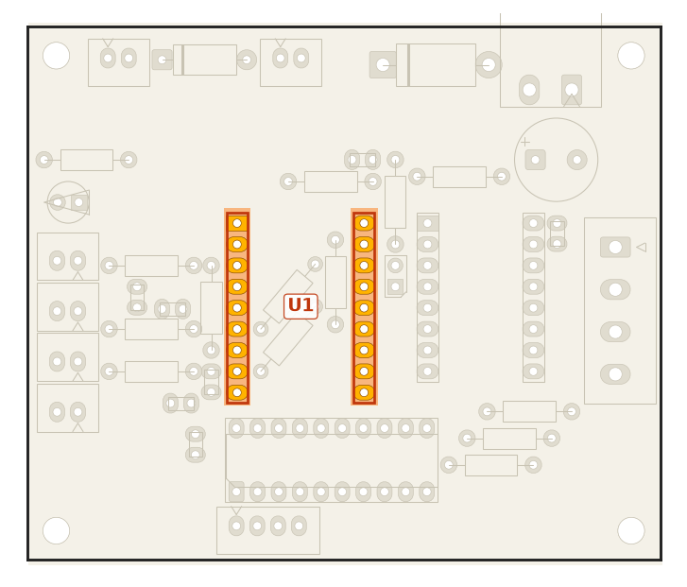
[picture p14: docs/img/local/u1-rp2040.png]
<table><tr><td align="center"><br><sub>Pinagem</sub></td><td align="center"><br><sub>Modelo 3D (KiCad)</sub></td><td align="center"><br><sub>Onde fica</sub></td></tr></table>

Vai em soquete (barra fêmea), nunca soldado direto. USB-C para **cima**, na borda superior. O desenho mostra a rede de cada pino na placa; os pinos em cinza ficam livres.

</div>

<div class="card" markdown="1">

### Driver TMC2209 (U4)

| Qtd | Referências | Valor | Comprar |
|---|---|---|---|
| 1 | U4 | TMC2209 | Módulo TMC2209 StepStick + 2 barras fêmea 1x8 2,54 mm |

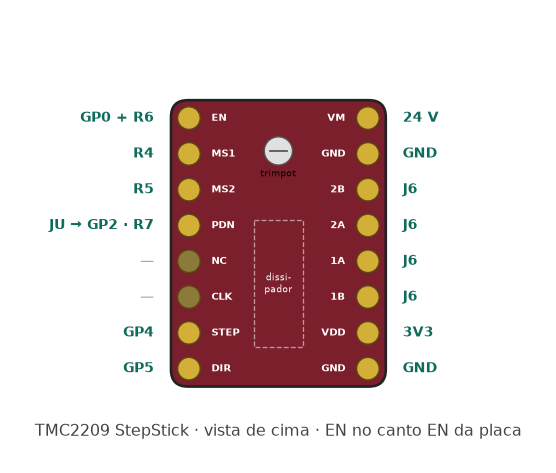
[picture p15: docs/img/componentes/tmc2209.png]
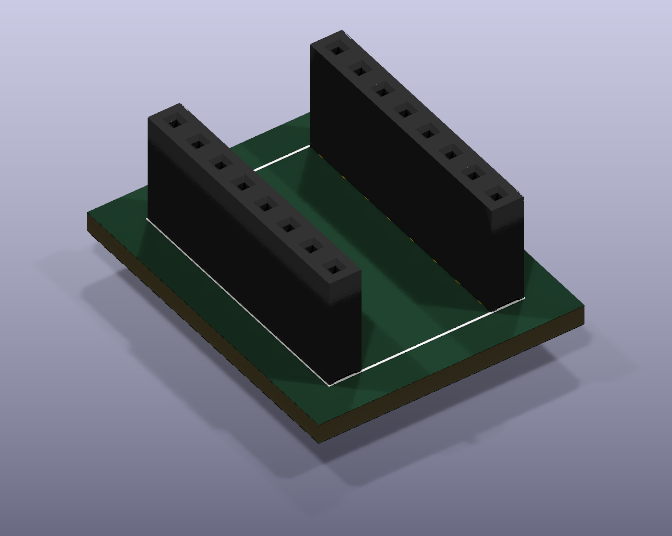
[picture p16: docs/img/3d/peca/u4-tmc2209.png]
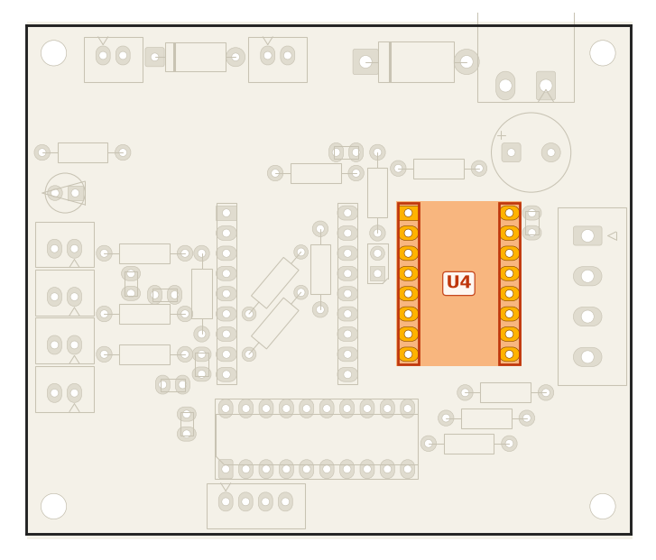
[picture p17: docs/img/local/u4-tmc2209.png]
<table><tr><td align="center"><br><sub>Pinagem</sub></td><td align="center"><br><sub>Modelo 3D (KiCad)</sub></td><td align="center"><br><sub>Onde fica</sub></td></tr></table>

Só nos nós com NEMA 17. Pino **EN** no canto marcado EN (ao lado do GP0 do RP), **VM** no canto marcado VM. Módulo do projeto: chip embaixo, trimpot e área do dissipador em cima, RSENSE R110 (0,11 Ω).

</div>

<div class="card" markdown="1">

### Buffer 74ACT245 (U2)

| Qtd | Referências | Valor | Comprar |
|---|---|---|---|
| 1 | U2 | 74ACT245 | SN74ACT245N DIP-20 (74HCT245N também serve) + soquete DIP-20 300 mil |

<table><tr><td align="center"><br><sub>Modelo 3D (KiCad)</sub></td><td align="center"><br><sub>Onde fica</sub></td></tr></table>

Vai em **soquete DIP-20**: o soquete é soldado e o CI encaixa depois. Chanfro/ponto do pino 1 para a **esquerda** (pino 1 = ilha quadrada, fileira de baixo). **Não** use 74HC245 (sem o T): em 5 V ele não reconhece os 3,3 V do RP como nível alto.

</div>

<div class="card" markdown="1">

### Diodo Schottky 1N5822 (D1)

| Qtd | Referências | Valor | Comprar |
|---|---|---|---|
| 1 | D1 | 1N5822 | Schottky 3 A 40 V, DO-201AD |

<table><tr><td align="center"><br><sub>Modelo 3D (KiCad)</sub></td><td align="center"><br><sub>Onde fica</sub></td></tr></table>

⚠️ Faixa do catodo para a **esquerda** (ilha quadrada). Invertido, a placa não liga. Perna grossa: furo de 1,6 mm.

</div>

<div class="card" markdown="1">

### TVS P6KE30A (D2)

| Qtd | Referências | Valor | Comprar |
|---|---|---|---|
| 1 | D2 | P6KE30A | TVS 600 W unidirecional, DO-15 |

<table><tr><td align="center"><br><sub>Modelo 3D (KiCad)</sub></td><td align="center"><br><sub>Onde fica</sub></td></tr></table>

⚠️ Faixa do catodo para a **esquerda** (ilha quadrada, lado do 24 V). Invertido, o TVS fica em curto com a 24 V.

</div>

<div class="card" markdown="1">

### LED 24 V (D3)

| Qtd | Referências | Valor | Comprar |
|---|---|---|---|
| 1 | D3 | LED 5 mm | LED comum 5 mm, qualquer cor (o de 3 mm usa os mesmos furos) |

<table><tr><td align="center"><br><sub>Modelo 3D (KiCad)</sub></td><td align="center"><br><sub>Onde fica</sub></td></tr></table>

Perna curta (catodo, lado chato) na ilha **quadrada**, à direita.

</div>

<div class="card" markdown="1">

### Capacitor eletrolítico 470 µF (C10)

| Qtd | Referências | Valor | Comprar |
|---|---|---|---|
| 1 | C10 | 470 µF 35 V | Eletrolítico 470 µF 35 V, Ø10 mm, passo 5 mm, 105 °C |

<table><tr><td align="center"><br><sub>Foto</sub></td><td align="center"><br><sub>Modelo 3D (KiCad)</sub></td><td align="center"><br><sub>Onde fica</sub></td></tr></table>

⚠️ Perna longa (+) na ilha **quadrada**, à esquerda. Faixa (−) à direita. O corpo fica a ~1,4 mm do conector J5: assente bem, sem inclinar.

</div>

<div class="card" markdown="1">

### Capacitores cerâmicos 100 nF

| Qtd | Referências | Valor | Comprar |
|---|---|---|---|
| 5 | C1 C2 C3 C6 C7 | 100 nF | Cerâmico 100 nF 50 V, passo 2,5 mm (marcação 104) |

<table><tr><td align="center"><br><sub>Foto</sub></td><td align="center"><br><sub>Modelo 3D (KiCad)</sub></td><td align="center"><br><sub>Onde fica</sub></td></tr></table>

Sem polaridade. Marcação no corpo: **104**. C3 fica junto ao VMOT do TMC; C6 fica embaixo do plugue USB (use peça baixa).

</div>

<div class="card" markdown="1">

### Capacitores cerâmicos 10 nF

| Qtd | Referências | Valor | Comprar |
|---|---|---|---|
| 2 | C4 C5 | 10 nF | Cerâmico 10 nF 50 V, passo 2,5 mm (marcação 103) |

<table><tr><td align="center"><br><sub>Foto</sub></td><td align="center"><br><sub>Modelo 3D (KiCad)</sub></td><td align="center"><br><sub>Onde fica</sub></td></tr></table>

Sem polaridade. Marcação no corpo: **103**. Filtro dos fins de curso.

</div>

<div class="card" markdown="1">

### Resistores 10 kΩ (1/4 W)

| Qtd | Referências | Valor | Comprar |
|---|---|---|---|
| 8 | R4 R5 R6 R7 R11 R12 R13 R14 | 10k | Resistor 1/4 W 5%, furos a 10,16 mm |

<table><tr><td align="center"><br><sub>Faixas de cor</sub></td><td align="center"><br><sub>Modelo 3D (KiCad)</sub></td><td align="center"><br><sub>Onde fica</sub></td></tr></table>

4 faixas (5%, corpo bege): **marrom, preto, laranja, dourado**. Em 5 faixas (1%, corpo geralmente azul): **marrom, preto, preto, vermelho, marrom**. Confira com o multímetro antes de soldar: marrom e vermelho se confundem com pouca luz. Todos deitados; R6 e R11 ficam na vertical do desenho e R13 e R14 inclinados 50°, paralelos. R6, R13 e R14 ficam embaixo do RP2040-Zero: solde **antes** da barra fêmea. R12 limita o LED (4k7 dá mais brilho).

</div>

<div class="card" markdown="1">

### Resistores 1 kΩ

| Qtd | Referências | Valor | Comprar |
|---|---|---|---|
| 2 | R2 R8 | 1k | Resistor 1/4 W 5%, furos a 10,16 mm |

<table><tr><td align="center"><br><sub>Faixas de cor</sub></td><td align="center"><br><sub>Modelo 3D (KiCad)</sub></td><td align="center"><br><sub>Onde fica</sub></td></tr></table>

4 faixas (5%, corpo bege): **marrom, preto, vermelho, dourado**. Em 5 faixas (1%, corpo geralmente azul): **marrom, preto, preto, marrom, marrom**. Confira com o multímetro antes de soldar: marrom e vermelho se confundem com pouca luz. Série dos fins de curso.

</div>

<div class="card" markdown="1">

### Resistores 100 kΩ

| Qtd | Referências | Valor | Comprar |
|---|---|---|---|
| 2 | R3 R15 | 100k | Resistor 1/4 W 5%, furos a 10,16 mm |

<table><tr><td align="center"><br><sub>Faixas de cor</sub></td><td align="center"><br><sub>Modelo 3D (KiCad)</sub></td><td align="center"><br><sub>Onde fica</sub></td></tr></table>

4 faixas (5%, corpo bege): **marrom, preto, amarelo, dourado**. Em 5 faixas (1%, corpo geralmente azul): **marrom, preto, preto, laranja, marrom**. Confira com o multímetro antes de soldar: marrom e vermelho se confundem com pouca luz. Pull-ups dos NTC: têm que ser 100k (é o `pullup_resistor` do cfg). O R15 fica deitado na vertical, ao lado do soquete do RP.

</div>

<div class="card" markdown="1">

### Resistor 47 kΩ

| Qtd | Referências | Valor | Comprar |
|---|---|---|---|
| 1 | R9 | 47k | Resistor 1/4 W 5%, furos a 10,16 mm |

<table><tr><td align="center"><br><sub>Faixas de cor</sub></td><td align="center"><br><sub>Modelo 3D (KiCad)</sub></td><td align="center"><br><sub>Onde fica</sub></td></tr></table>

4 faixas (5%, corpo bege): **amarelo, violeta, laranja, dourado**. Em 5 faixas (1%, corpo geralmente azul): **amarelo, violeta, preto, vermelho, marrom**. Confira com o multímetro antes de soldar: marrom e vermelho se confundem com pouca luz. Parte de cima do divisor da 24 V.

</div>

<div class="card" markdown="1">

### Resistor 5,6 kΩ

| Qtd | Referências | Valor | Comprar |
|---|---|---|---|
| 1 | R10 | 5k6 | Resistor 1/4 W 5%, furos a 10,16 mm |

<table><tr><td align="center"><br><sub>Faixas de cor</sub></td><td align="center"><br><sub>Modelo 3D (KiCad)</sub></td><td align="center"><br><sub>Onde fica</sub></td></tr></table>

4 faixas (5%, corpo bege): **verde, azul, vermelho, dourado**. Em 5 faixas (1%, corpo geralmente azul): **verde, azul, preto, marrom, marrom**. Confira com o multímetro antes de soldar: marrom e vermelho se confundem com pouca luz. Parte de baixo do divisor; fica embaixo do plugue USB.

</div>

<div class="card" markdown="1">

### Conector 24 V (J5)

| Qtd | Referências | Valor | Comprar |
|---|---|---|---|
| 1 | J5 | 24V | Conector plugável 2EDG 2 vias, passo 5,08 mm, macho 90° 2EDGRC na placa + plugue 2EDGK com parafusos |

<table><tr><td align="center"><br><sub>Modelo 3D (KiCad)</sub></td><td align="center"><br><sub>Onde fica</sub></td></tr></table>

Plugue entra pela **borda de cima** (a frente do macho passa ~2,5 mm da borda, para o plugue não bater na placa). +24 V à esquerda, GND à direita. Pinos de 1 mm em furo de 1,6 mm.

</div>

<div class="card" markdown="1">

### Conector do motor (J6)

| Qtd | Referências | Valor | Comprar |
|---|---|---|---|
| 1 | J6 | MOTOR | Conector plugável 2EDG 4 vias, passo 5,08 mm, macho vertical 2EDGVC na placa + plugue 2EDGK com parafusos |

<table><tr><td align="center"><br><sub>Modelo 3D (KiCad)</sub></td><td align="center"><br><sub>Onde fica</sub></td></tr></table>

Plugue encaixa **por cima**; a parede alta do macho fica para dentro da placa e o fio sai para a **direita**. De cima para baixo: 2B, 2A, 1A, 1B. Pinos de 1 mm em furo de 1,6 mm.

</div>

<div class="card" markdown="1">

### Conector DM556 (J4)

| Qtd | Referências | Valor | Comprar |
|---|---|---|---|
| 1 | J4 | DM556 | JST XH 4 vias 2,5 mm vertical (B4B-XH-A + fêmea XHP-4 + 4 terminais) |

<table><tr><td align="center"><br><sub>Foto (JST XH)</sub></td><td align="center"><br><sub>Modelo 3D (KiCad)</sub></td><td align="center"><br><sub>Onde fica</sub></td></tr></table>

Da esquerda para a direita: 5V, PUL−, DIR−, ENA−. Encaixe o corpo no contorno da serigrafia.

</div>

<div class="card" markdown="1">

### Conectores NTC (J3, J8)

| Qtd | Referências | Valor | Comprar |
|---|---|---|---|
| 2 | J3 J8 | NTC1, NTC2 | JST XH 2 vias 2,5 mm vertical (B2B-XH-A + XHP-2 + 2 terminais) |

<table><tr><td align="center"><br><sub>Foto (JST XH)</sub></td><td align="center"><br><sub>Modelo 3D (KiCad)</sub></td><td align="center"><br><sub>Onde fica</sub></td></tr></table>

Sinal à direita, GND à esquerda. O NTC não tem polaridade. J3 = motor do TMC2209, J8 = motor do DM556 (só com dois motores na placa).

</div>

<div class="card" markdown="1">

### Conectores dos fins de curso (J1, J2)

| Qtd | Referências | Valor | Comprar |
|---|---|---|---|
| 2 | J1 J2 | FIM1, FIM2 | JST XH 2 vias 2,5 mm vertical (B2B-XH-A + XHP-2 + 2 terminais) |

<table><tr><td align="center"><br><sub>Foto (JST XH)</sub></td><td align="center"><br><sub>Modelo 3D (KiCad)</sub></td><td align="center"><br><sub>Onde fica</sub></td></tr></table>

Sinal à direita, GND à esquerda. A chave fecha o pino para o GND. O corpo do XH fica a ~0,9 mm da perna de R2/R3/R8.

</div>

<div class="card" markdown="1">

### Conectores das ventoinhas (J7, J9)

| Qtd | Referências | Valor | Comprar |
|---|---|---|---|
| 2 | J7 J9 | FAN 24V, FAN2 24V | JST XH 2 vias 2,5 mm vertical (B2B-XH-A + XHP-2 + 2 terminais) |

<table><tr><td align="center"><br><sub>Foto (JST XH)</sub></td><td align="center"><br><sub>Modelo 3D (KiCad)</sub></td><td align="center"><br><sub>Onde fica</sub></td></tr></table>

+24 V à esquerda, GND à direita. As duas sempre ligadas: J7 na ventoinha do TMC2209, J9 na do DM556 ou da caixa.

</div>

<div class="card" markdown="1">

### Header de UART (JU)

| Qtd | Referências | Valor | Comprar |
|---|---|---|---|
| 1 | JU | UART | Barra de pinos macho 1x2 2,54 mm + 1 jumper |

<table><tr><td align="center"><br><sub>Foto</sub></td><td align="center"><br><sub>Modelo 3D (KiCad)</sub></td><td align="center"><br><sub>Onde fica</sub></td></tr></table>

Aberto na primeira ligação. Fechado = UART do TMC2209 no GP2, pelo pino 4 do soquete (ver [capítulo 5](05-conectores-e-jumpers.md#ju--uart-do-tmc2209)).

</div>

<div class="card" markdown="1">

### Fixação (H1–H4)

| Qtd | Referências | Valor | Comprar |
|---|---|---|---|
| 4 | H1 H2 H3 H4 | M3 | Parafuso M3 + espaçador |

<table><tr><td align="center"><br><sub>Foto</sub></td><td align="center"><br><sub>Onde fica</sub></td></tr></table>

Furos de 3,2 mm nos quatro cantos, num retângulo de 69 × 57 mm. Cabe cabeça M3 comum (~5,5 mm); com arruela, o H1 (ao lado do J7) e o H2 (ao lado do J5) ficam justos: use arruela só por baixo.

</div>

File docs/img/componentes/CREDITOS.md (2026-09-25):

# Créditos das fotos de componentes

Todas as fotos vêm do Wikimedia Commons. Licença e autor foram conferidos no `extmetadata` (campos `LicenseShortName` e `Artist`) da API do Commons em 2026-09-25.
Modificações: todas foram redimensionadas para no máximo 800 px de largura, com os metadados EXIF removidos. As obras derivadas de arquivos CC BY-SA ficam sob a mesma licença do original.

| arquivo | título original no Commons | autor | licença | URL da página do arquivo |
|---|---|---|---|---|
| capacitor-ceramico.jpg | File:Soviet ceramic disc capacitors 01.jpg | Retired electrician | CC0 | https://commons.wikimedia.org/wiki/File:Soviet_ceramic_disc_capacitors_01.jpg |
| capacitor-eletrolitico.jpg | File:Electronic-Component-Elec-Capacitors.jpg | Evan-Amos | Domínio público | https://commons.wikimedia.org/wiki/File:Electronic-Component-Elec-Capacitors.jpg |
| conector-xh.jpg | File:Balancer Buchse XH.JPG | Laurenz Wagner | CC BY 3.0 | https://commons.wikimedia.org/wiki/File:Balancer_Buchse_XH.JPG |
| barra-femea.jpg | File:8 Pin Female Header.jpg | oomlout | CC BY-SA 2.0 | https://commons.wikimedia.org/wiki/File:8_Pin_Female_Header.jpg |
| barra-macho-jumper.jpg | File:Assorted Electronic Jumpers.jpg | MarcoTangerino | Domínio público | https://commons.wikimedia.org/wiki/File:Assorted_Electronic_Jumpers.jpg |
| fim-de-curso.jpg | File:Mini Microswitch - SPDT (Lever) (12781998883).jpg | SparkFun Electronics from Boulder, USA | CC BY 2.0 | https://commons.wikimedia.org/wiki/File:Mini_Microswitch_-_SPDT_(Lever)_(12781998883).jpg |
| parafuso-espacador.jpg | File:Abstandsbolzen, verschiedene Typen.JPG | wdwd | CC BY-SA 4.0 | https://commons.wikimedia.org/wiki/File:Abstandsbolzen,_verschiedene_Typen.JPG |

## Ilustrações próprias

`resistor-*.png`, `rp2040-zero.png` e `tmc2209.png` são desenhos gerados a partir da placa (faixas de cor
do valor e pinagem por rede), não fotos. Estão sob a mesma licença do projeto.

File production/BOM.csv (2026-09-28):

Qtd | Referencias | Valor | Descricao
5 | C1 C2 C3 C6 C7 | 100nF | Capacitor ceramico 100 nF 50 V, passo 2,5 mm
2 | C4 C5 | 10nF | Capacitor ceramico 10 nF 50 V, passo 2,5 mm
1 | C10 | 470uF 35V | Capacitor eletrolitico 470 uF 35 V, 10 mm de diametro, passo 5 mm (105 C)
1 | D1 | 1N5822 | Diodo Schottky 1N5822 3 A 40 V (DO-201AD) - polaridade 24 V
1 | D3 | LED 24V | LED 5 mm (qualquer cor) - indica 24 V; o de 3 mm usa os mesmos furos
1 | D2 | P6KE30A | TVS P6KE30A unidirecional (DO-15) - protecao 24 V
1 | J5 | 24V | Conector plugavel 2EDG 2 vias 5,08 mm: macho 90 graus 2EDGRC-5.08-2P + plugue 2EDGK-5.08-2P
1 | J4 | DM556 | Conector JST XH 4 vias 2,5 mm, vertical (B4B-XH-A + femea XHP-4 + 4 terminais): 5V, PUL-, DIR-, ENA-
1 | J7 | FAN 24V | Conector JST XH 2 vias 2,5 mm, vertical (B2B-XH-A + femea XHP-2 + 2 terminais)
1 | J9 | FAN2 24V | Conector JST XH 2 vias 2,5 mm, vertical (B2B-XH-A + femea XHP-2 + 2 terminais)
1 | J1 | FIM1 | Conector JST XH 2 vias 2,5 mm, vertical (B2B-XH-A + femea XHP-2 + 2 terminais)
1 | J2 | FIM2 | Conector JST XH 2 vias 2,5 mm, vertical (B2B-XH-A + femea XHP-2 + 2 terminais)
1 | J6 | MOTOR | Conector plugavel 2EDG 4 vias 5,08 mm: macho vertical 2EDGVC-5.08-4P + plugue 2EDGK-5.08-4P
1 | J3 | NTC1 | Conector JST XH 2 vias 2,5 mm, vertical (B2B-XH-A + femea XHP-2 + 2 terminais)
1 | J8 | NTC2 | Conector JST XH 2 vias 2,5 mm, vertical (B2B-XH-A + femea XHP-2 + 2 terminais)
1 | JU | UART | Barra de pinos macho 1x2 2,54 mm + 1 jumper (fechado = UART do TMC2209 no GP2, pino 4 do soquete)
2 | R3 R15 | 100k | Resistor 1/4 W 5%, deitado, furos a 10,16 mm
8 | R4 R5 R6 R7 R11 R12 R13 R14 | 10k | Resistor 1/4 W 5%, deitado, furos a 10,16 mm
2 | R2 R8 | 1k | Resistor 1/4 W 5%, deitado, furos a 10,16 mm
1 | R9 | 47k | Resistor 1/4 W 5%, deitado, furos a 10,16 mm
1 | R10 | 5k6 | Resistor 1/4 W 5%, deitado, furos a 10,16 mm
1 | U2 | 74ACT245 | SN74ACT245N DIP-20 (74HCT245N tambem serve), vai no soquete DIP-20
1 | U1 | RP2040-Zero | Waveshare RP2040-Zero
1 | U4 | TMC2209 | Modulo TMC2209 StepStick (so no no com NEMA17)
2 | - | Barra fêmea 1x9 2,54 mm | Soquete do RP2040-Zero
2 | - | Barra fêmea 1x8 2,54 mm | Soquete do TMC2209
1 | - | Soquete DIP-20 300 mil (7,62 mm) | Para o 74ACT245 (U2): o soquete e soldado, o CI encaixa
4 | H1-H4 | Parafuso M3 + espaçador | Fixação
2 | - | NTC 100k B3950 (com fio) | Temperatura dos motores, vão no J3 e no J8 (o J8 só com dois motores na placa)
2 | - | Chave fim de curso (NA ou NF) | Vão no J1/J2 (ligam o pino ao GND)
1 | - | Fusível de lâmina 2 A 32 V DC (ATO ou mini) | Na caixa de fusíveis central, um só para esta placa (docs/06)

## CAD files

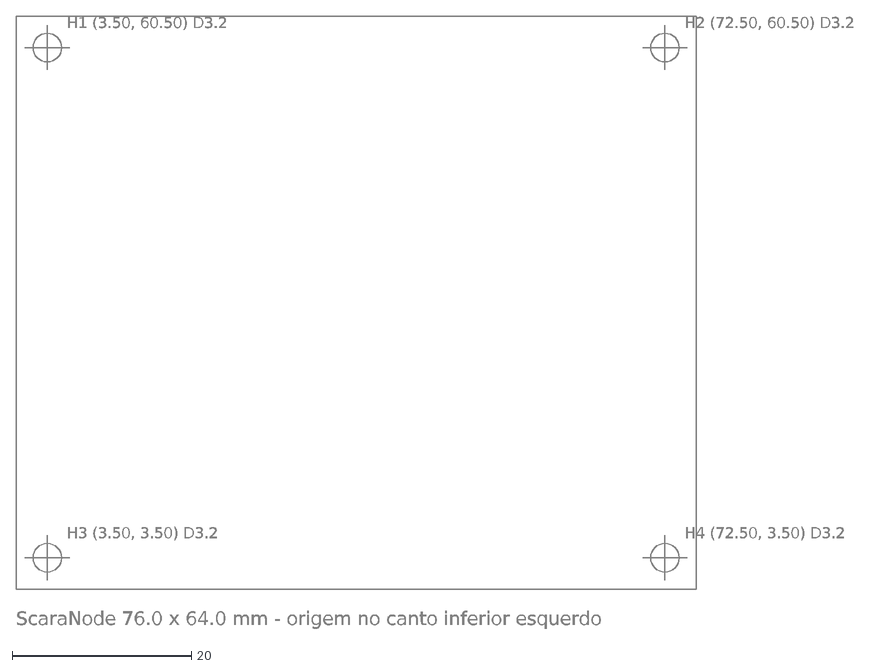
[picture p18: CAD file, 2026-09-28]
production/ScaraNode-mecanico.dxf
H1 (3.50, 60.50) D3.2
H2 (72.50, 60.50) D3.2
H3 (3.50, 3.50) D3.2
H4 (72.50, 3.50) D3.2
ScaraNode 76.0 x 64.0 mm - origem no canto inferior esquerdo

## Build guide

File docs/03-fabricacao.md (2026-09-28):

# 3. Fabricação (fresa CNC)

A placa é de **face única**: todo o cobre fica embaixo (B.Cu), e as peças vão do lado de cima, sem cobre.
As regras foram escolhidas para uma fresa de desempenho desconhecido, então valem para praticamente
qualquer CNC caseira.

## Regras do desenho

| Regra | Valor |
|---|---|
| Isolação entre cobres (vão) | **0,60 mm** em todo lugar (mínimo medido: 0,601 mm) |
| Trilhas | sinal 1,2 · 3,3 V 1,2 · 5 V 1,5 · motor 1,8 · 24 V e GND de potência 2,5 mm |
| Ilhas | soquetes e headers ovais 2,6 × 1,8 · resistores 2,0 · capacitores 1,8 × 2,4 · conectores 2EDG 2,4 × 3,6 · C10 2,4 mm |
| Anel de cobre em volta do furo | mínimo **0,40 mm** em todos os furos |
| Cobre até a borda | 0,5 mm |
| Plano de GND | preenche o que sobra. Ilhas soltas ficam, porque sobra menos cobre para a fresa tirar. Alívio térmico em X nos pads de GND. |

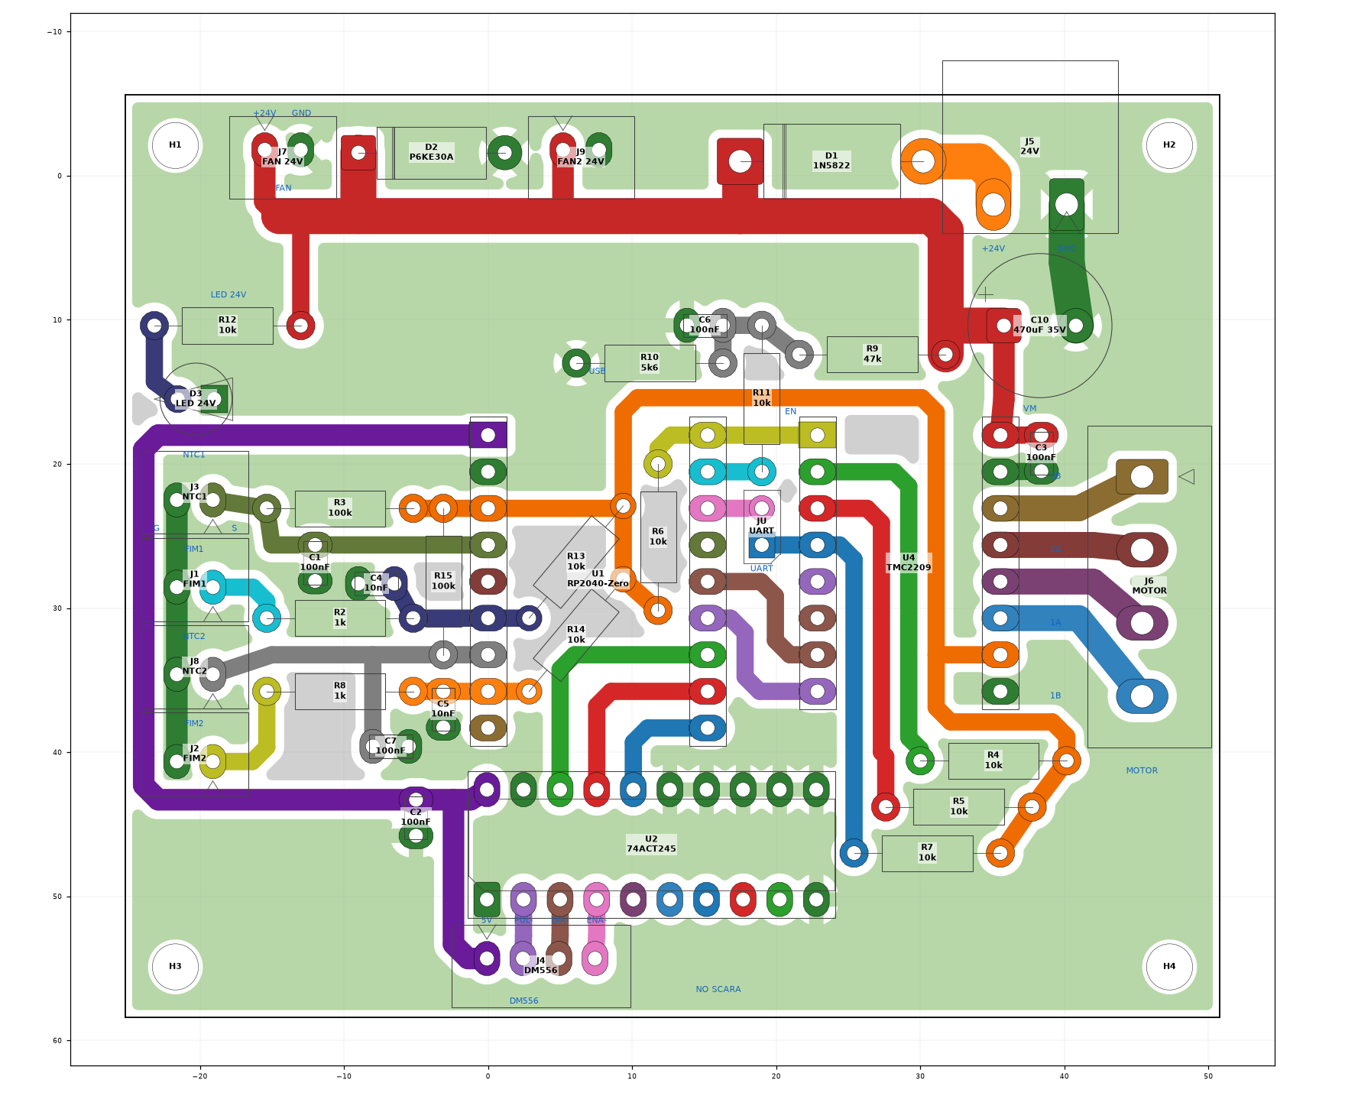
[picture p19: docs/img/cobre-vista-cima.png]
Face de cobre vista de cima

<p align="center"><em>Face de cobre vista de cima (através da placa). Verde = GND ligado, cinza = ilha solta, cores = redes.</em></p>

## Ferramentas

| Etapa | Ferramenta | Observação |
|---|---|---|
| Isolação | V-bit 20–30° com ponta de 0,1–0,2 mm, ou fresa reta de 0,4–0,6 mm | Acima de 0,6 mm não passa entre ilhas vizinhas. Com 0,4 mm, faça 2 passadas. |
| Furos finos | broca **1,0 mm** de metal duro | **118 furos**: R, C, DIP, LED, D2, soquetes, JST XH, headers, C10 |
| Furos grossos | broca **1,6 mm** | **8 furos**: D1 (2), conector J5 (2) e conector J6 (4) |
| Contorno e M3 | fresa reta de 1,5–2,0 mm | Contorno em 3–4 passadas. Os 4 furos de 3,2 mm saem com essa fresa (mill holes). |

A placa usa só **duas brocas**. Os furos foram agrupados na v13, e as ilhas cresceram onde foi preciso
para manter o anel de 0,4 mm.

**Folgas:**
- A peça mais justa é a **barra fêmea** (pino de 0,64 mm quadrado em furo de 1,0 mm). Os furos precisam
  estar bem posicionados: fure uma fileira de 9 e teste a barra antes de fazer o resto.
- A peça mais folgada é o **conector 2EDG** (pino de ~1,0 mm em furo de 1,6 mm). O corpo assenta na placa e a
  ilha oval de 2,4 × 3,6 mm segura.

## Arquivos de produção

**Para mandar ao operador da CNC:** [`production/cnc/ScaraNode-v18-CNC.zip`](../production/cnc/ScaraNode-v18-CNC.zip).
Tem um arquivo por ferramenta, com a operação e a ferramenta no nome (isolação, uma furação por broca, contorno),
numerados na ordem da fresa, e um PDF com o resumo, as ferramentas, o aviso de espelhamento e a imagem de conferência.

Já gerados em [`production/gerber/`](../production/gerber/):

| Arquivo | Conteúdo |
|---|---|
| `ScaraNode-B_Cu.gbl` | cobre (face única), **visto por cima**, através da placa |
| `ScaraNode-Edge_Cuts.gm1` | contorno 76 × 64 mm |
| `ScaraNode.drl` | furação Excellon: mm, absoluto, decimal, mesma origem do Gerber |
| `ScaraNode-drl_map.pdf` | mapa de furos por diâmetro |
| `ScaraNode-B_Cu-ESPELHADO.pdf` / `.png` | cobre já espelhado: como a placa fica olhando o lado do cobre |
| `ScaraNode-F_Silkscreen.gto` | serigrafia do lado das peças (só para conferência, não fresa) |

Para regerar depois de editar a placa no KiCad:

```sh
PCB=hardware/ScaraNode.kicad_pcb; OUT=production/gerber
kicad-cli pcb export gerbers --layers B.Cu,Edge.Cuts,F.SilkS --no-x2 --no-netlist \
    --use-drill-file-origin -o $OUT/ $PCB
kicad-cli pcb export drill --format excellon --excellon-units mm --excellon-zeros-format decimal \
    --drill-origin absolute --generate-map --map-format pdf -o $OUT/ $PCB
kicad-cli pcb export pdf --layers B.Cu,Edge.Cuts --mirror -o $OUT/ScaraNode-B_Cu-ESPELHADO.pdf $PCB
```

## Desenho mecânico

Placa **76 × 64 mm**. Furos M3 de **3,2 mm**, com centro a 3,5 mm das bordas. Origem no canto **inferior
esquerdo** da vista de cima (Y para cima, como no CAD):

| Furo | X (mm) | Y (mm) | Posição |
|---|---|---|---|
| H3 | 3,5 | 3,5 | inferior esquerdo |
| H4 | 72,5 | 3,5 | inferior direito |
| H1 | 3,5 | 60,5 | superior esquerdo |
| H2 | 72,5 | 60,5 | superior direito |

- Os quatro formam um retângulo de **69 × 57 mm** entre centros (v18: até a v17 o H2 ficava 14,5 mm mais baixo,
  porque o borne J5 ocupava o canto).
- DXF para a caixa ou o suporte: [`production/ScaraNode-mecanico.dxf`](../production/ScaraNode-mecanico.dxf)
  (camadas `CONTORNO`, `FUROS`, `CENTRO`, `COTAS`; mm).

## ⚠️ Espelhamento: o erro que inutiliza a placa

O Gerber da face de baixo é desenhado **visto por cima**. Se você fresa com o cobre virado para cima, o
CAM (no FlatCAM: *Mirror*, eixo Y) tem que mostrar a placa **igual à imagem abaixo**:

- conector de 24 V (J5) e conector do motor (J6) à **esquerda**
- NTC e fins de curso à **direita**
- USB do RP2040-Zero **em cima**

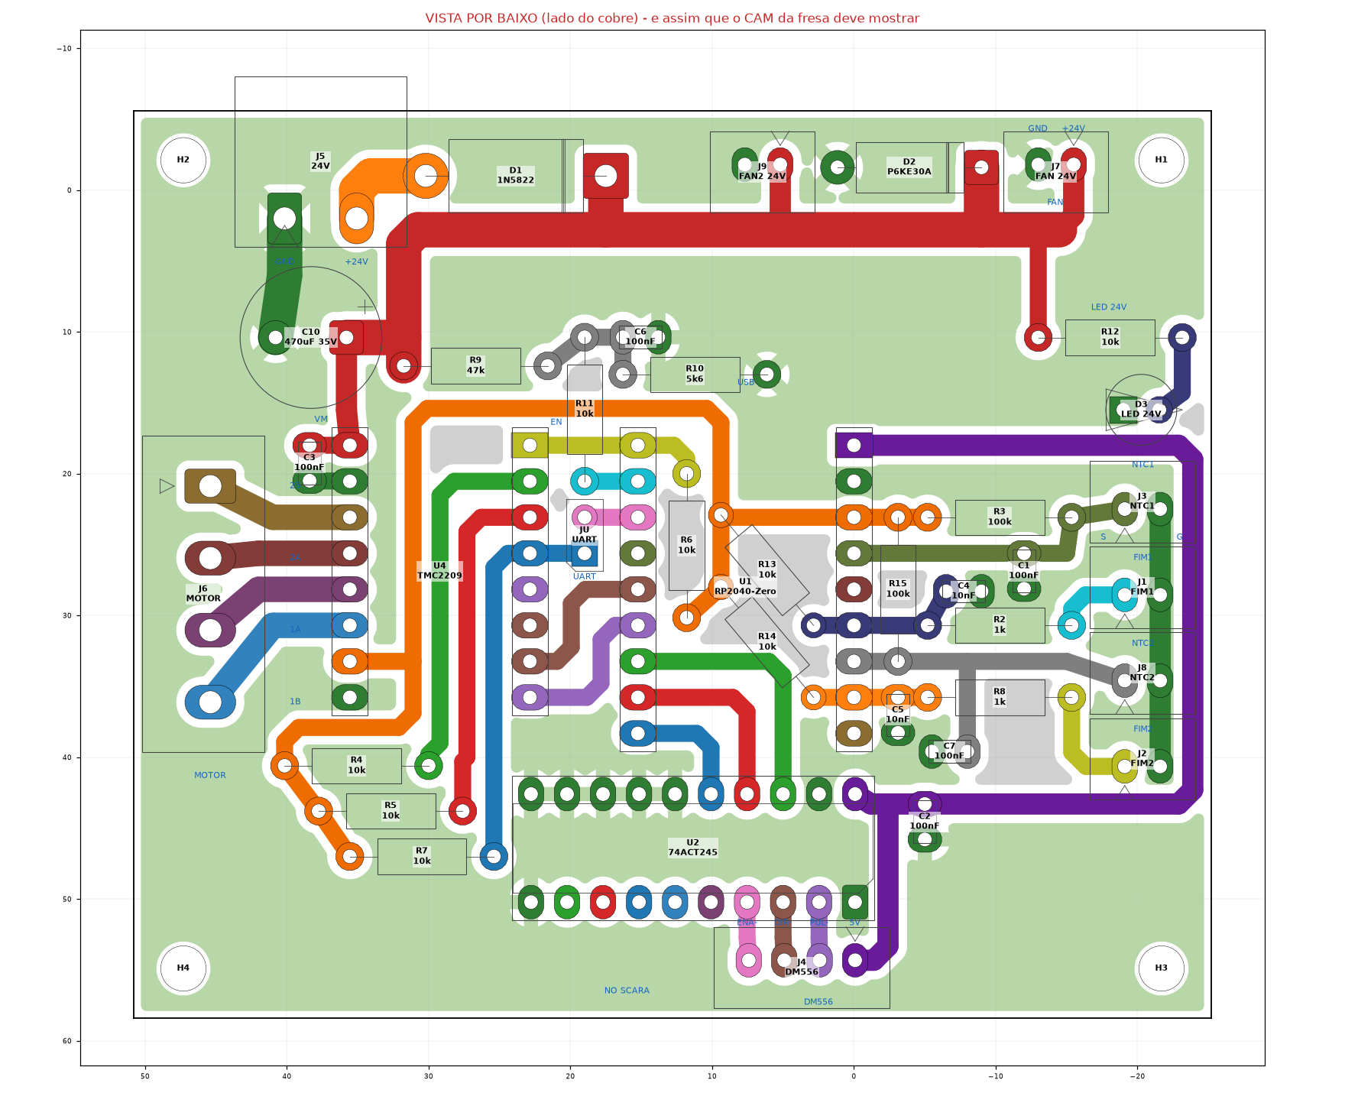
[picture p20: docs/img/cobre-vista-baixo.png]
Cobre espelhado, vista por baixo


Se o CAM mostrar a placa igual à [vista de cima](#regras-do-desenho), o espelhamento está errado e
nenhum módulo vai encaixar.

## Conferência depois de fresar

1. Com o multímetro em continuidade, confira que nenhuma trilha vizinha está em curto, principalmente
   entre as fileiras dos soquetes e perto das ilhas de GND.
2. Encaixe a barra fêmea de 9 pinos nos furos do RP2040-Zero antes de soldar qualquer peça.
3. Compare a placa com a `ScaraNode-B_Cu-ESPELHADO.png`, olhando pelo lado do cobre.

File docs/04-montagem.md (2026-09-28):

# 4. Montagem

Peças do lado **sem cobre**, solda do lado do cobre. Monte **da peça mais baixa para a mais alta**: assim a
placa apoia plana na bancada a cada etapa.

<p align="center">Mapa de montagem</p>

## Antes de começar

- Placa fresada e conferida ([capítulo 3](03-fabricacao.md#conferência-depois-de-fresar)).
- Teste o encaixe: uma barra fêmea de 9 pinos nos furos do RP2040-Zero e o conector 2EDG nos furos de 1,6 mm.
- Ferro de 30–60 W, estanho 0,8 mm com fluxo, alicate de corte rente.
- Separe as peças pelo [BOM](02-lista-de-materiais.md) e confira os valores dos resistores com o multímetro.

## Sequência

| Passo | Peça | Onde | Cuidado |
|:-:|---|:-:|---|
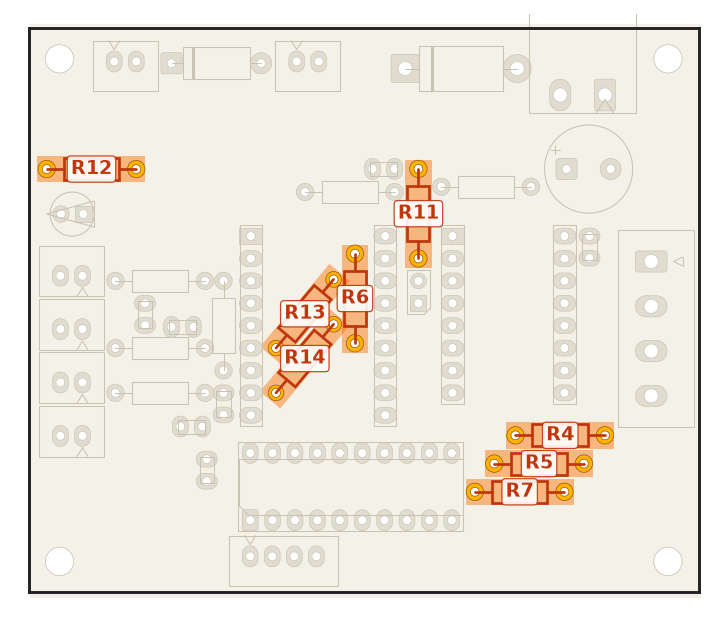
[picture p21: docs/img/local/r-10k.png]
| 1 | **R13, R14** (10k) |  | Ficam **embaixo do RP2040-Zero**: têm que entrar antes da barra fêmea. R13 e R14 inclinados 50°, paralelos; o corpo do R14 passa por cima da trilha STP. |
| 2 | **R6** (10k) |  | Também fica embaixo do RP. Aproveite e monte os outros 10k (R4, R5, R7, R11, R12). |
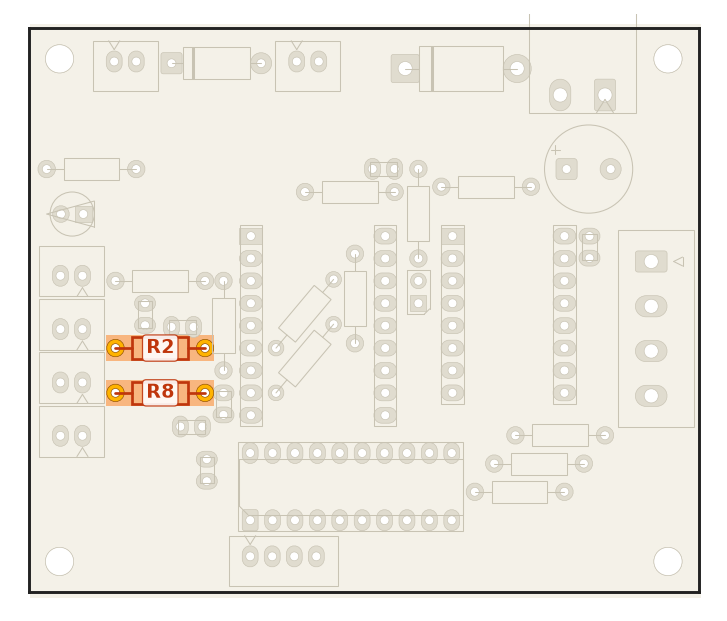
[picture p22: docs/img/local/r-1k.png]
| 3 | **Demais resistores** |  | R2, R8 (1k) · R3, R15 (100k) · R9 (47k) · R10 (5k6). Todos deitados, sem polaridade; o R15 fica na vertical, ao lado da barra fêmea da esquerda do RP. |
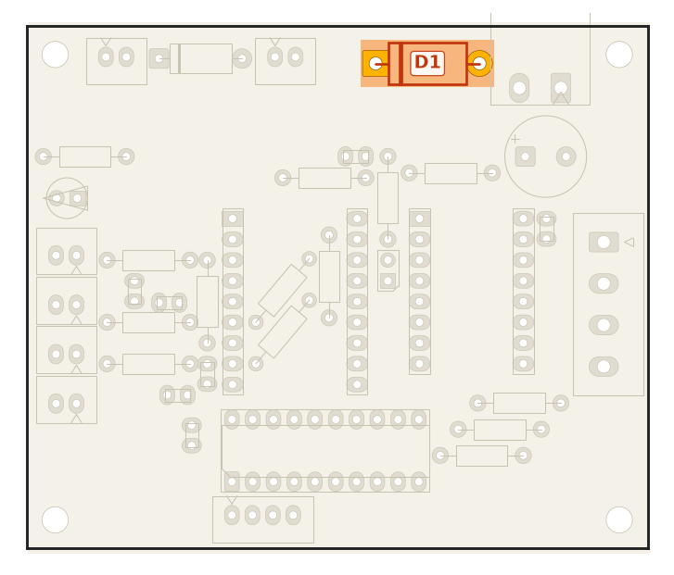
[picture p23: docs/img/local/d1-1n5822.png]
| 4 | **D1** 1N5822 |  | ⚠️ Faixa do catodo para a **esquerda** (ilha quadrada). |
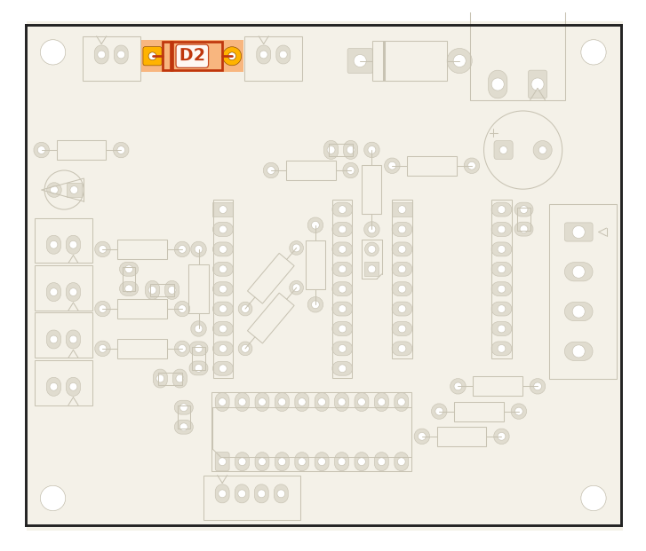
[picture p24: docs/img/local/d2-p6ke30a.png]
| 5 | **D2** P6KE30A |  | ⚠️ Faixa do catodo para a **esquerda** (ilha quadrada). |
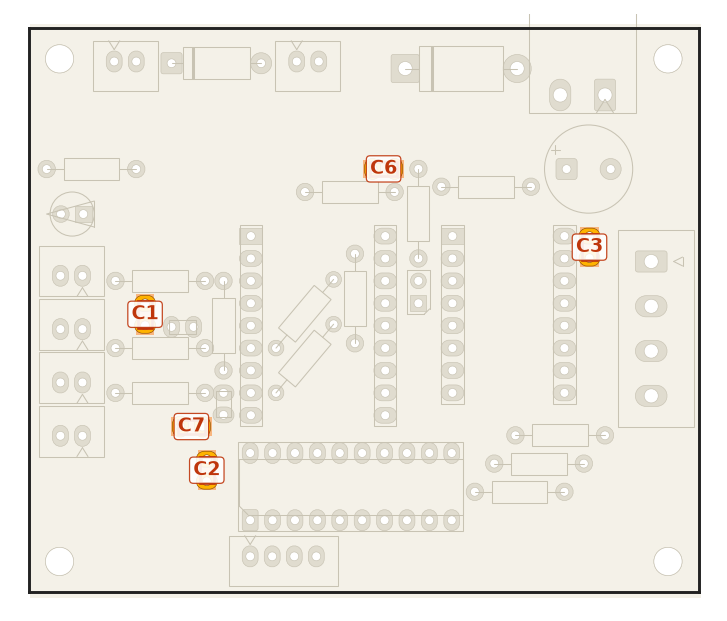
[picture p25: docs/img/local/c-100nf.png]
| 6 | **Cerâmicos** C1–C7 |  | Sem polaridade. 100 nF: C1, C2, C3, C6, C7 · 10 nF: C4, C5. |
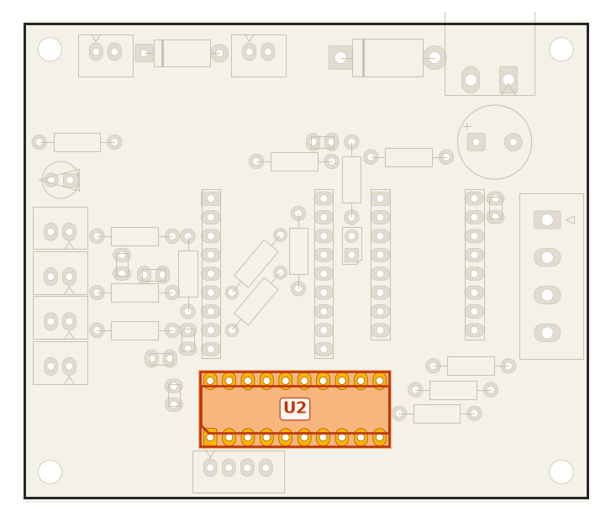
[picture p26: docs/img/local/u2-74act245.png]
| 7 | **Soquete DIP-20** do U2 |  | Chanfro do soquete para a **esquerda** (lado do pino 1). Solde dois cantos, confira que assentou e depois o resto. O CI só entra no passo 14. |
| 8 | **Barras fêmea** do RP (2 × 1x9) e do TMC (2 × 1x8) |  | Encaixe o módulo nas barras **antes** de soldar, para as fileiras ficarem paralelas. Solde as pontas, confira o prumo e depois o resto. |
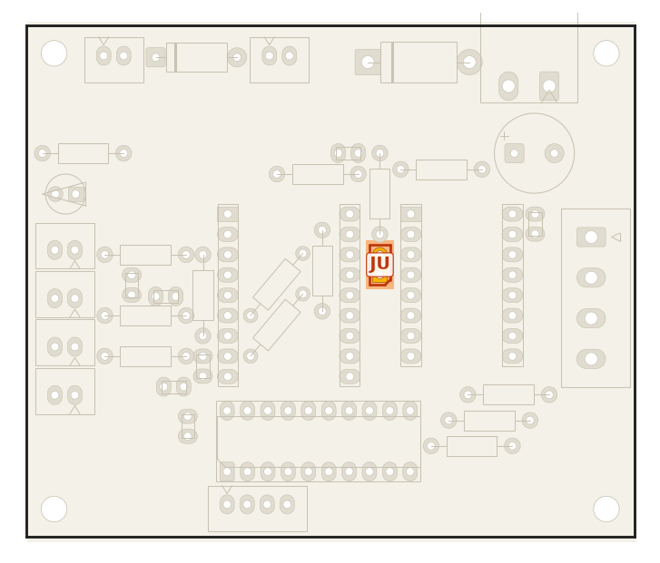
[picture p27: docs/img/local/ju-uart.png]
| 9 | **JU** (1x2) |  | Pinos curtos para baixo. Sem jumper por enquanto. |
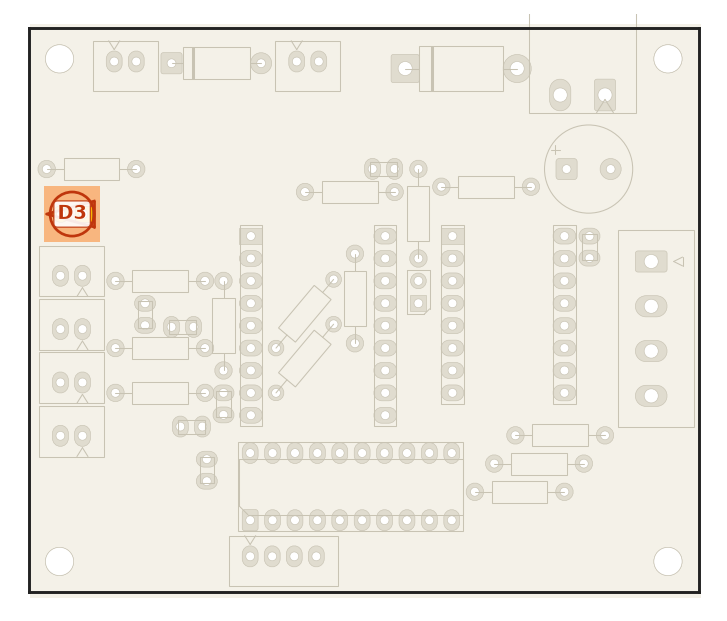
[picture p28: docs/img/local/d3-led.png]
| 10 | **LED D3** |  | Perna curta (catodo, lado chato) na ilha **quadrada**, à direita. |
| 11 | **JST XH** J1, J2, J3, J4, J7, J8, J9 |  | Corpo sobre o contorno da serigrafia. J1–J3 ficam a ~0,9 mm das pernas de R2/R3/R8. |
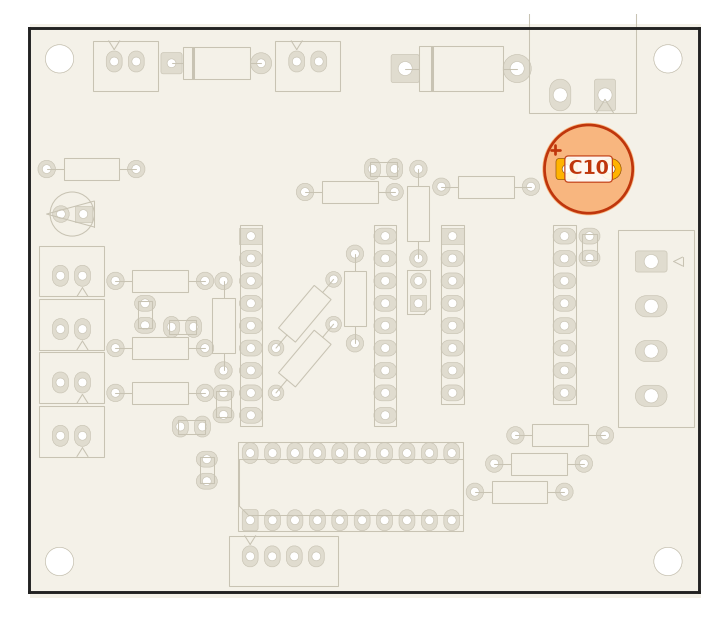
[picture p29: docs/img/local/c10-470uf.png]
| 12 | **C10** 470 µF |  | ⚠️ Perna longa (+) na ilha **quadrada**, à esquerda. Assente bem: fica a ~0,8 mm da cabeça do M3 do H2 e a ~1,2 mm do borne J5. |
| 13 | **Conectores 2EDG** J5 e J6 |  | J5 (24 V, macho 90°): a abertura para a **borda de cima**. J6 (motor, macho vertical): parede alta para **dentro** da placa, o fio do plugue sai para a **direita**. Confira com o plugue encaixado antes de soldar. |
| 14 | **74ACT245** no soquete |  | Chanfro/ponto do pino 1 para a **esquerda**, igual ao soquete. Endireite as pernas na bancada antes. |
| 15 | **Módulos** (só depois da [conferência](#conferência-antes-de-energizar)) |  | RP2040-Zero com USB para cima. TMC2209 com EN no canto EN e VM no canto VM. |

## Alturas e interferências

- **Embaixo do plugue USB-C** do RP só há peças deitadas (C6, R10, R11), com menos de 3 mm de altura.
- O RP2040-Zero fica a ~8,5 mm da placa, em cima da barra fêmea; R6, R13 e R14 ficam embaixo dele.
- **C10** (Ø10 mm) fica a ~1,4 mm do corpo do J5: assente bem, sem inclinar.

## Polaridades: resumo

| Peça | Marca na peça | Ilha quadrada | Lado |
|---|---|---|---|
| D1 1N5822 | faixa = catodo | catodo | esquerda |
| D2 P6KE30A | faixa = catodo | catodo | esquerda |
| D3 LED | lado chato / perna curta = catodo | catodo | direita |
| C10 | faixa (−); perna longa (+) | **+** | esquerda |
| U2 74ACT245 | chanfro / ponto = pino 1 | pino 1 (GND) | esquerda |
| RP2040-Zero | USB-C | — | para cima |
| TMC2209 | serigrafia EN / VM do módulo | — | EN ao lado do GP0 |

## Conferência antes de energizar

Sem módulos, sem jumpers e com o C10 descarregado:

| Medida (multímetro) | Esperado |
|---|---|
| Continuidade +24 V × GND no J5 | **não pode apitar** (um bip curto é o C10 carregando) |
| 5V × GND e 3V3 × GND no soquete do RP | **não pode apitar** |
| Pino EN do soquete do TMC × 3V3 | ~10 kΩ (R6) |
| GP27 × 3V3 e GP15 × 3V3 no soquete do RP | ~10 kΩ (R13, R14) |
| GND do J3/J1/J8/J2 × GND do J5 | continuidade |
| Pino 1 × pino 20 do soquete do U2 (GND × 5V) | não pode apitar |

No módulo TMC2209, **antes** de fechar o JU: confirme com o multímetro ou na serigrafia que o pino 4 (posição do
MS3) é o PDN_UART. A placa liga a UART nesse pino desde a v18.

Próximo passo: [8. Primeira ligação e testes](08-testes.md).

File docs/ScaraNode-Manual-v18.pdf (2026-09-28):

# ScaraNode

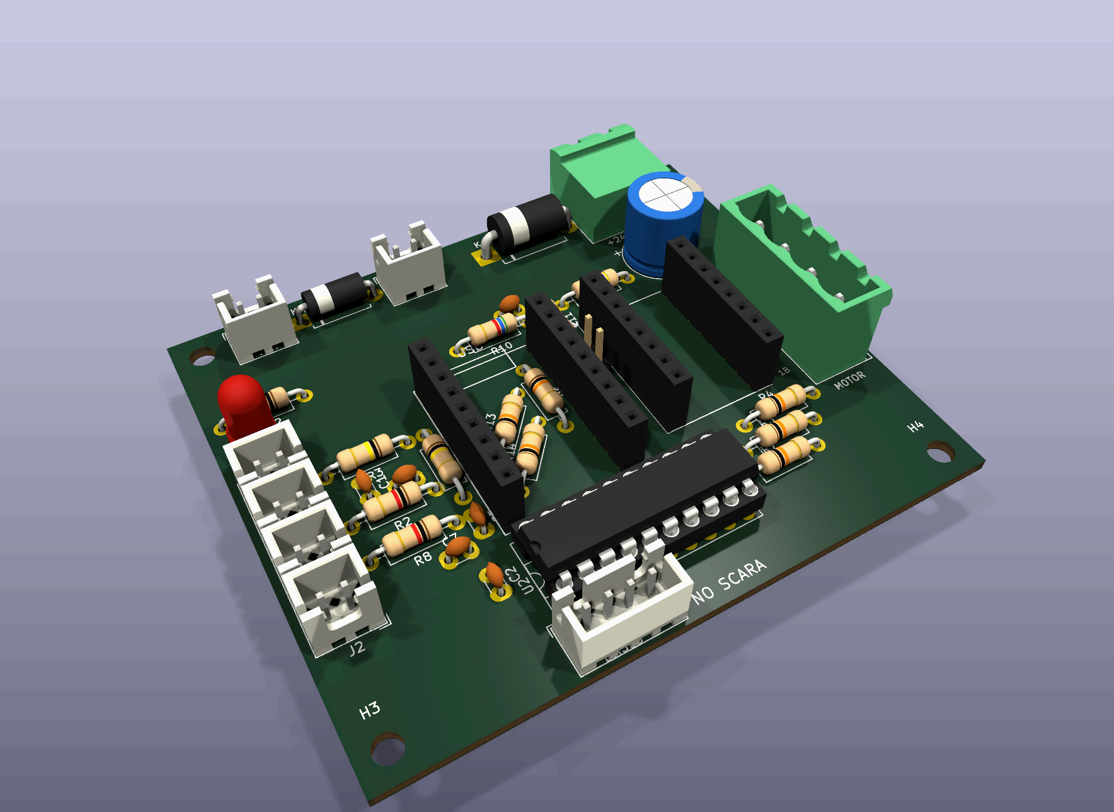
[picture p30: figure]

PROJETISTA Daniel M. Torres | REVISÃO v18 | DATA 27/09/2026
PLACA 76 × 64 mm · FR-4 1,6 · 1 face | FERRAMENTA KiCad 10.0.6 | VALIDAÇÃO 128 pinos · ERC 0 · paridade 0 · DRC de cobre 0

M A N U A L T É C N I C O D A P L A C A

## Nó de motor Klipper para braço SCARA · RP2040-Zero + TMC2209 ou DM556 · face única fresada

ScaraNode · Rev. v18 · 27/09/2026 | Projetista: Daniel M. Torres | 2 / 44

# ScaraNode — Manual da Placa

Placa de nó de motor para um braço SCARA com Klipper: um RP2040-Zero por eixo, controlando um TMC2209 no soquete (NEMA 17) e/ou um DM556 externo (NEMA 23), com canais independentes. Face única, feita para fresar em casa.

Projeto | ScaraNode — nó de motor Klipper
Projetista | Daniel M. Torres
Revisão | v18
Data da revisão | 27/09/2026
Placa | 76 × 64 mm · FR-4 1,6 mm · cobre só na face de baixo (B.Cu)
Ferramenta | KiCad 10.0.6 · placa gerada por ferramenta própria em Python; fonte editável: hardware/ScaraNode.kicad_pcb
Estado | Validada: 124 pinos conferidos contra o esquemático (ERC 0, paridade 0), DRC de cobre sem erro, 0 ligações faltando e nenhuma curva de trilha de 90°; onde os courtyards se sobrepõem, corpos a ≥ 0,10 mm (menor 0,30 mm); vão mínimo 0,60 mm, anel mínimo 0,40 mm

ScaraNode · Rev. v18 · 27/09/2026 | Projetista: Daniel M. Torres | 3 / 44

## Capítulos

# | Capítulo | Conteúdo

1 | Visão geral | O que a placa faz, especificações, blocos, diagrama
2 | Lista de materiais | Cada peça com foto, modelo 3D e onde encaixa
3 | Fabricação | Regras de fresa, ferramentas, Gerber, espelhamento
4 | Montagem | Ordem de solda passo a passo, polaridades, conferência
5 | Conectores, pinagem e jumpers | O que ligar em cada pino, jumper JU
6 | Circuitos e cálculos | Cada bloco explicado, com as contas
7 | Firmware Klipper | Gravação do RP2040 e printer.cfg
8 | Primeira ligação e testes | Roteiro de ligação, diagnóstico, limites da placa
— | Histórico de revisões | Decisões de projeto, revisão por revisão

PDF: ScaraNode-Manual-v18.pdf , gerado destes mesmos arquivos. Esquemático: ScaraNode-Esquematico-v18.pdf .

## Convenções deste manual

Vista de cima = lado das peças, com o USB do RP2040-Zero para cima. Todas as imagens de montagem usam essa vista. A única vista espelhada é a do cobre, no capítulo de fabricação. Coordenadas em mm, com origem no canto superior esquerdo do RP2040-Zero (mesmo referencial da ferramenta de geração).
Nomes de rede ( 24V , VSENSE , STP …) são os mesmos da placa no KiCad.
⚠️ marca o que queima peça ou inutiliza a placa se for feito errado.

ScaraNode · Rev. v18 · 27/09/2026 | Projetista: Daniel M. Torres | 4 / 44

# Sumário

### 1. 1. Visão geral

### 2. 2. Lista de materiais

### 3. 3. Fabricação (fresa CNC)

### 4. 4. Montagem

### 5. 5. Conectores, pinagem e jumpers

### 6. 6. Circuitos e cálculos

### 7. 7. Firmware Klipper

### 8. 8. Primeira ligação e testes

### 9. Histórico de revisões

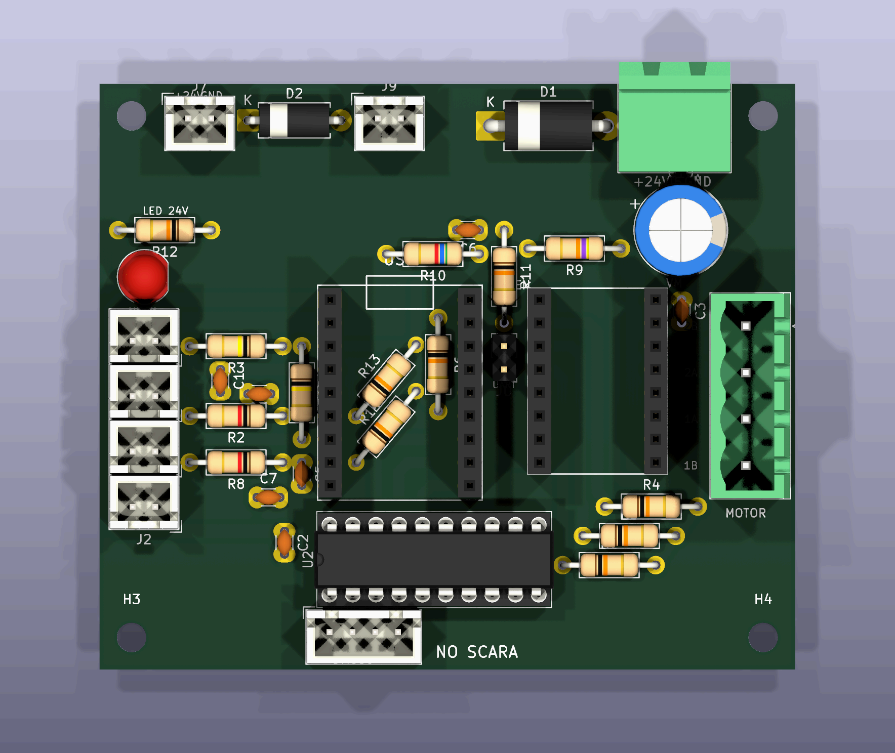
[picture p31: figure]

ScaraNode · Rev. v18 · 27/09/2026 | Projetista: Daniel M. Torres | 5 / 44

# 1. Visão geral

## O que a placa faz

Cada nó controla um motor do SCARA. O RP2040-Zero roda o firmware do Klipper e conversa com o host (Raspberry Pi ou PC) pelo USB. O host coordena os quatro nós:

Nó | Junta | Motor | Driver
J1 | ombro | NEMA 23 | DM556 externo, pelo conector J4
J2 | cotovelo | NEMA 17 | TMC2209 no soquete U4
Z | vertical | NEMA 23 | DM556 externo, pelo conector J4
J3 | rotação da ferramenta | NEMA 17 | TMC2209 no soquete U4

É a mesma placa nos quatro nós. Só muda o que se monta nela:

Variante | Monta | Fica vazio
TMC2209 (J2, J3) | tudo, inclusive C3, R4–R7, JU, J6 e o módulo TMC2209 | J4 pode ficar sem cabo (o 74ACT245 não atrapalha)

## Especificações

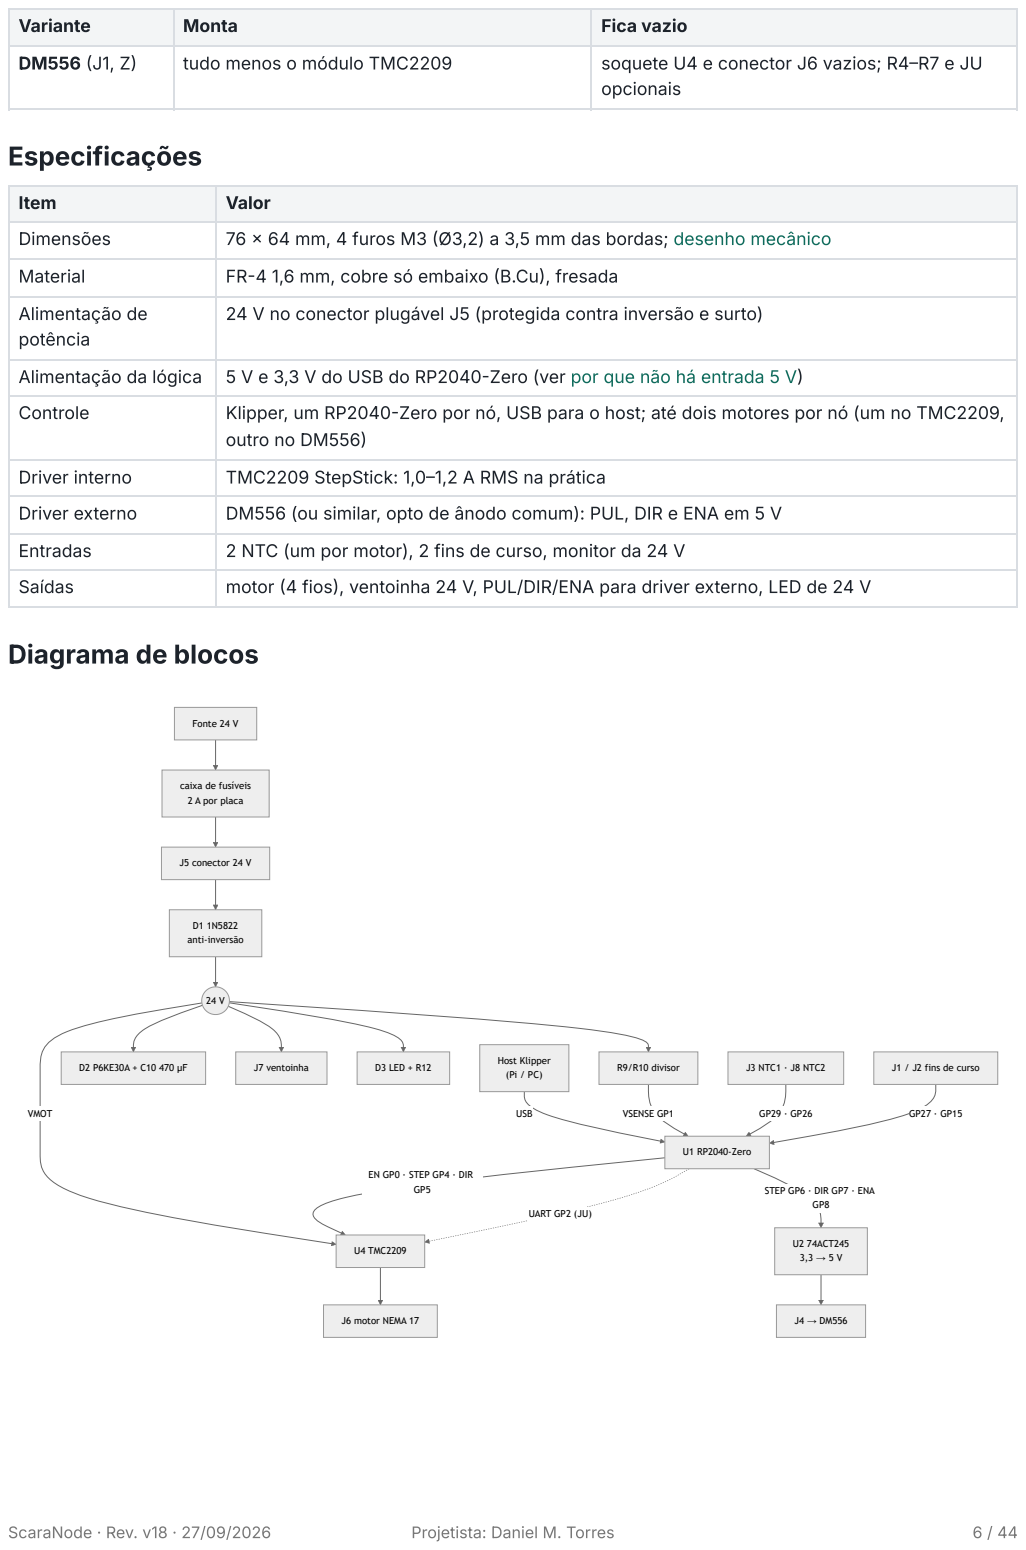
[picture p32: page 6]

Variante | Monta | Fica vazio
DM556 (J1, Z) | tudo menos o módulo TMC2209 | soquete U4 e conector J6 vazios; R4–R7 e JU opcionais

Item | Valor
Dimensões | 76 × 64 mm, 4 furos M3 (Ø3,2) a 3,5 mm das bordas; desenho mecânico
Material | FR-4 1,6 mm, cobre só embaixo (B.Cu), fresada
Alimentação de potência | 24 V no conector plugável J5 (protegida contra inversão e surto)

Alimentação da lógica | 5 V e 3,3 V do USB do RP2040-Zero (ver por que não há entrada 5 V)
Controle | Klipper, um RP2040-Zero por nó, USB para o host; até dois motores por nó (um no TMC2209, outro no DM556)

Driver interno | TMC2209 StepStick: 1,0–1,2 A RMS na prática
Driver externo | DM556 (ou similar, opto de ânodo comum): PUL, DIR e ENA em 5 V
Entradas | 2 NTC (um por motor), 2 fins de curso, monitor da 24 V
Saídas | motor (4 fios), ventoinha 24 V, PUL/DIR/ENA para driver externo, LED de 24 V

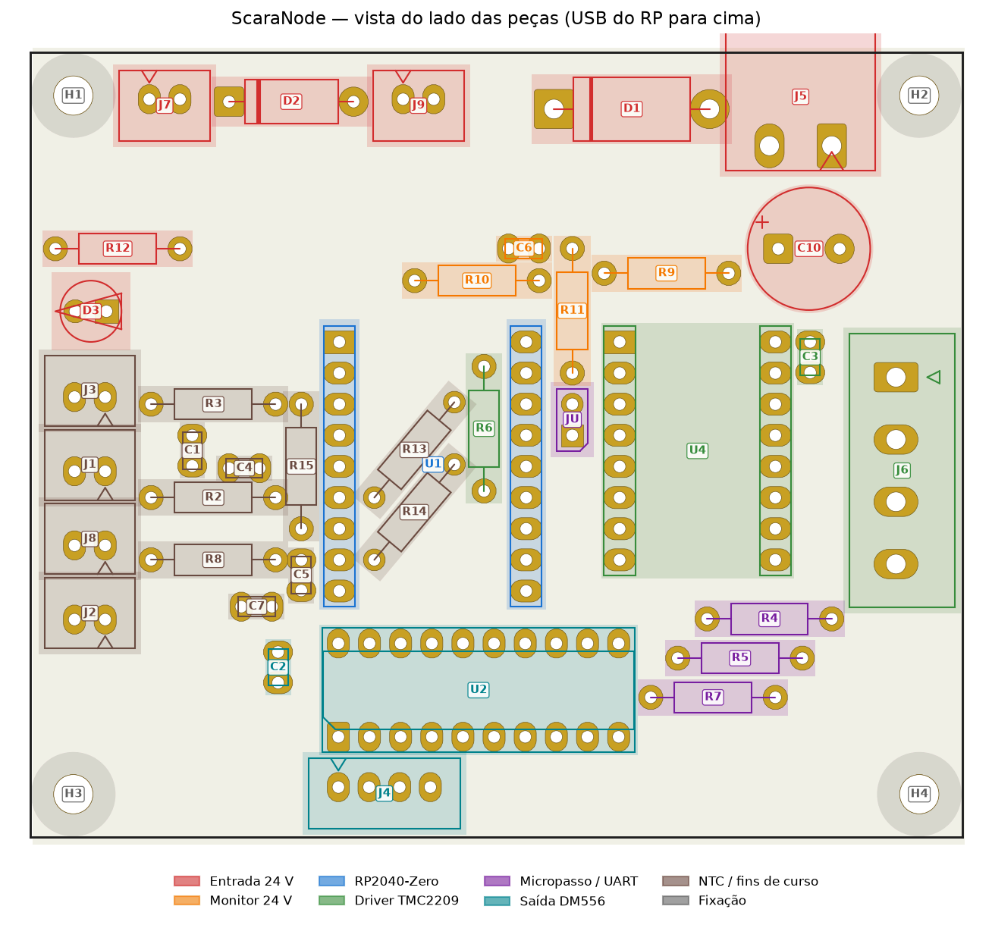
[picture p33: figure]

ScaraNode · Rev. v18 · 27/09/2026 | Projetista: Daniel M. Torres | 7 / 44

## Blocos e peças

Bloco | Peças | Função
Entrada 24 V | J5, D1, C10, D2, D3, R12, J7, J9 | Recebe a 24 V (fusível de 2 A por placa na caixa central). D1 protege contra inversão, D2 (TVS) contra surto, C10 guarda a energia de frenagem do motor, D3 acende com 24 V, J7 alimenta a ventoinha.
Monitor de 24 V | R9, R10, C6, R11 | Divisor 47k/5k6 leva 24 V a ~2,5 V no GP1. Se a potência cair, o Klipper faz M112.
Cérebro | U1 RP2040-Zero | Gera STEP/DIR, lê os sensores, fala com o host por USB. Fornece o 5 V (do USB) e o 3,3 V (regulador do módulo).
Driver TMC2209 | U4, R6, C3, J6 | Módulo StepStick. R6 deixa o driver desligado até o Klipper assumir. C3 desacopla o VMOT. J6 é o conector do motor.
Micropasso / UART | R4, R5, R7, JU | Pull-ups de 10k fixos em MS1/MS2 (R4, R5): endereço UART 3, ou 1/16 em standalone. JU fechado liga o GP2 ao PDN_UART (pino 4), que tem o R7 de pull-up.

ScaraNode · Rev. v18 · 27/09/2026 | Projetista: Daniel M. Torres | 8 / 44
Bloco | Peças | Função
Saída DM556 | U2, C2, J4 | Buffer de 3,3 para 5 V. As saídas afundam PUL−, DIR− e ENA− do DM556 (ânodo comum no 5 V).
NTC e fins de curso | J1, J2, J3, J8, R2, R3, R8, R13, R14, R15, C1, C4, C5, C7 | Dois NTC com pull-up de 100k no ADC. Chaves para GND com pull-up de 10k e filtro RC.

Detalhes e contas no capítulo 6. Circuitos.

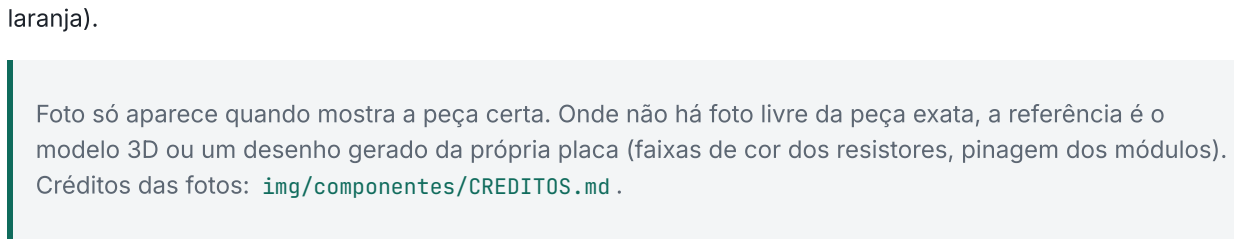
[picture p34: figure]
laranja).; Créditos das fotos: img/componentes/CREDITOS.md .

ScaraNode · Rev. v18 · 27/09/2026 | Projetista: Daniel M. Torres | 9 / 44

# 2. Lista de materiais

A lista de compras oficial é production/BOM.csv , gerada direto da placa. Este capítulo mostra cada item com uma imagem de referência, o modelo 3D usado no KiCad e o lugar exato na placa (vista de cima, peça em

Foto só aparece quando mostra a peça certa. Onde não há foto livre da peça exata, a referência é o modelo 3D ou um desenho gerado da própria placa (faixas de cor dos resistores, pinagem dos módulos).

## Resumo

Qtd | Item | Referências
1 | Waveshare RP2040-Zero | U1
1 | Módulo TMC2209 StepStick (só nós NEMA 17) | U4
1 | SN74ACT245N DIP-20 | U2
1 | Soquete DIP-20 300 mil | U2
1 | Schottky 1N5822 | D1
1 | TVS P6KE30A | D2
1 | LED 5 mm | D3
1 | Eletrolítico 470 µF 35 V | C10
5 | Cerâmico 100 nF (104) | C1 C2 C3 C6 C7
2 | Cerâmico 10 nF (103) | C4 C5
8 | Resistor 10k 1/4 W | R4 R5 R6 R7 R11 R12 R13 R14
2 | Resistor 1k 1/4 W | R2 R8
2 | Resistor 100k 1/4 W | R3 R15
1 | Resistor 47k 1/4 W | R9
1 | Resistor 5k6 1/4 W | R10
1 | Conector 2EDG 2 vias 5,08 mm (macho 90° 2EDGRC + plugue 2EDGK) | J5
1 | Conector 2EDG 4 vias 5,08 mm (macho vertical 2EDGVC + plugue 2EDGK) | J6
1 | JST XH 4 vias | J4
6 | JST XH 2 vias | J1 J2 J3 J7 J8 J9
1 | Barra macho 1x2 + 1 jumper | JU
2 | Barra fêmea 1x9 | soquete do U1
2 | Barra fêmea 1x8 | soquete do U4
4 | Parafuso M3 + espaçador | H1–H4

Fora da placa: um ou dois NTC 100k B3950 com fio (J3, J8), duas chaves fim de curso NA ou NF (J1/J2), ventoinha 24 V (J7), cabo USB-C, fonte de 24 V, fusível de lâmina de 2 A só para esta placa na caixa de fusíveis central (capítulo 6). Nos nós J1 e Z: driver DM556 e motor NEMA 23.

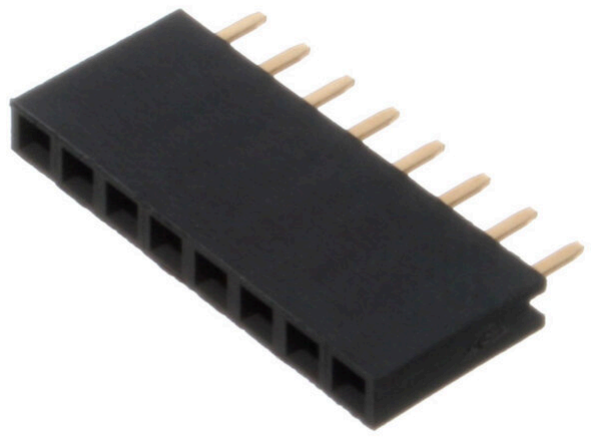
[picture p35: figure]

ScaraNode · Rev. v18 · 27/09/2026 | Projetista: Daniel M. Torres | 10 / 44
Barra fêmea (soquetes do RP e do TMC) | Chave fim de curso

## Item por item

RP2040-Zero (U1)

Qtd | Referências | Valor | Comprar
1 | U1 | RP2040-Zero | Waveshare RP2040-Zero + 2 barras fêmea 1x9 2,54 mm
Pinagem | Modelo 3D (KiCad) | Onde fica

Vai em soquete (barra fêmea), nunca soldado direto. USB-C para cima, na borda superior. O desenho mostra a rede de cada pino na placa; os pinos em cinza ficam livres.

Driver TMC2209 (U4)

Qtd | Referências | Valor | Comprar
1 | U4 | TMC2209 | Módulo TMC2209 StepStick + 2 barras fêmea 1x8 2,54 mm
Pinagem | Modelo 3D (KiCad) | Onde fica

Só nos nós com NEMA 17. Pino EN no canto marcado EN (ao lado do GP0 do RP), VM no canto marcado VM. Módulo do projeto: chip embaixo, trimpot e área do dissipador em cima, RSENSE R110 (0,11 Ω).

ScaraNode · Rev. v18 · 27/09/2026 | Projetista: Daniel M. Torres | 11 / 44

Buffer 74ACT245 (U2)

Qtd | Referências | Valor | Comprar
1 | U2 | 74ACT245 | SN74ACT245N DIP-20 (74HCT245N também serve) + soquete DIP-20 300 mil
Modelo 3D (KiCad) | Onde fica

Vai em soquete DIP-20: o soquete é soldado e o CI encaixa depois. Chanfro/ponto do pino 1 para a esquerda (pino 1 = ilha quadrada, fileira de baixo). Não use 74HC245 (sem o T): em 5 V ele não reconhece os 3,3 V do RP como nível alto.

Diodo Schottky 1N5822 (D1)

Qtd | Referências | Valor | Comprar
1 | D1 | 1N5822 | Schottky 3 A 40 V, DO-201AD
Modelo 3D (KiCad) | Onde fica

⚠️ Faixa do catodo para a esquerda (ilha quadrada). Invertido, a placa não liga. Perna grossa: furo de 1,6 mm.

ScaraNode · Rev. v18 · 27/09/2026 | Projetista: Daniel M. Torres | 12 / 44

TVS P6KE30A (D2)

Qtd | Referências | Valor | Comprar
1 | D2 | P6KE30A | TVS 600 W unidirecional, DO-15
Modelo 3D (KiCad) | Onde fica

⚠️ Faixa do catodo para a esquerda (ilha quadrada, lado do 24 V). Invertido, o TVS fica em curto com a 24 V.

LED 24 V (D3)

Qtd | Referências | Valor | Comprar
1 | D3 | LED 5 mm | LED comum 5 mm, qualquer cor (o de 3 mm usa os mesmos furos)
Modelo 3D (KiCad) | Onde fica

Perna curta (catodo, lado chato) na ilha quadrada, à direita.

ScaraNode · Rev. v18 · 27/09/2026 | Projetista: Daniel M. Torres | 13 / 44

Capacitor eletrolítico 470 µF (C10)

Qtd | Referências | Valor | Comprar
1 | C10 | 470 µF 35 V | Eletrolítico 470 µF 35 V, Ø10 mm, passo 5 mm, 105 °C
Foto | Modelo 3D (KiCad) | Onde fica

⚠️ Perna longa (+) na ilha quadrada, à esquerda. Faixa (−) à direita. O corpo fica a ~1,4 mm do conector J5: assente bem, sem inclinar.

Capacitores cerâmicos 100 nF

Qtd | Referências | Valor | Comprar
5 | C1 C2 C3 C6 C7 | 100 nF | Cerâmico 100 nF 50 V, passo 2,5 mm (marcação 104)
Foto | Modelo 3D (KiCad) | Onde fica

Sem polaridade. Marcação no corpo: 104. C3 fica junto ao VMOT do TMC; C6 fica embaixo do plugue USB (use peça baixa).

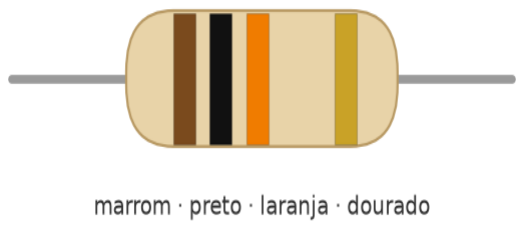
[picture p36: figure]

ScaraNode · Rev. v18 · 27/09/2026 | Projetista: Daniel M. Torres | 14 / 44

Capacitores cerâmicos 10 nF

Qtd | Referências | Valor | Comprar
2 | C4 C5 | 10 nF | Cerâmico 10 nF 50 V, passo 2,5 mm (marcação 103)
Foto | Modelo 3D (KiCad) | Onde fica

Sem polaridade. Marcação no corpo: 103. Filtro dos fins de curso.

Resistores 10 kΩ (1/4 W)

Qtd | Referências | Valor | Comprar
8 | R4 R5 R6 R7 R11 R12 R13 R14 | 10k | Resistor 1/4 W 5%, furos a 10,16 mm
Faixas de cor | Modelo 3D (KiCad) | Onde fica

4 faixas (5%, corpo bege): marrom, preto, laranja, dourado. Em 5 faixas (1%, corpo geralmente azul): marrom, preto, preto, vermelho, marrom. Confira com o multímetro antes de soldar: marrom e vermelho se confundem com pouca luz. Todos deitados; R6 e R11 ficam na vertical do desenho e R13 e R14 inclinados 50°, paralelos. R6, R13 e R14 ficam embaixo do RP2040-Zero: solde antes da barra fêmea. R12 limita o LED (4k7 dá mais brilho).

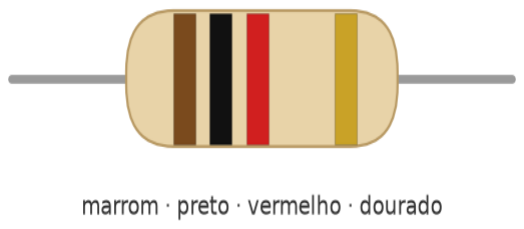
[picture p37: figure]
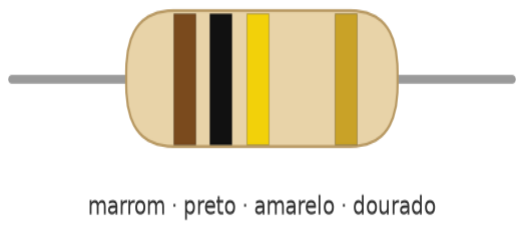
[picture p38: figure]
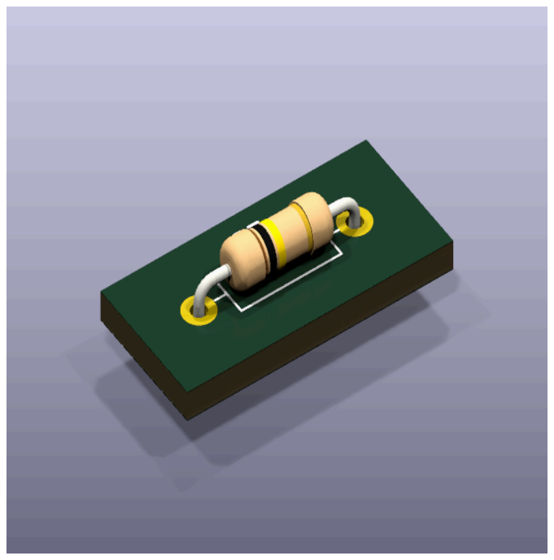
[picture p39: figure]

ScaraNode · Rev. v18 · 27/09/2026 | Projetista: Daniel M. Torres | 15 / 44

Resistores 1 kΩ

Qtd | Referências | Valor | Comprar
2 | R2 R8 | 1k | Resistor 1/4 W 5%, furos a 10,16 mm
Faixas de cor | Modelo 3D (KiCad) | Onde fica

4 faixas (5%, corpo bege): marrom, preto, vermelho, dourado. Em 5 faixas (1%, corpo geralmente azul): marrom, preto, preto, marrom, marrom. Confira com o multímetro antes de soldar: marrom e vermelho se confundem com pouca luz. Série dos fins de curso.

Resistores 100 kΩ

Qtd | Referências | Valor | Comprar
2 | R3 R15 | 100k | Resistor 1/4 W 5%, furos a 10,16 mm
Faixas de cor | Modelo 3D (KiCad) | Onde fica

4 faixas (5%, corpo bege): marrom, preto, amarelo, dourado. Em 5 faixas (1%, corpo geralmente azul): marrom, preto, preto, laranja, marrom. Confira com o multímetro antes de soldar: marrom e vermelho se confundem com pouca luz. Pull-ups dos NTC: têm que ser 100k (é o pullup_resistor do cfg). O R15 fica deitado na vertical, ao lado do soquete do RP.

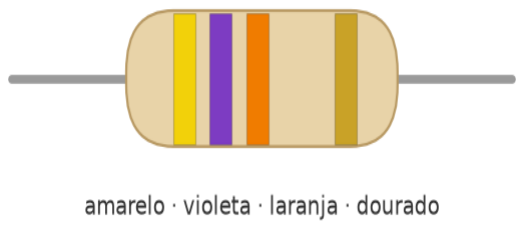
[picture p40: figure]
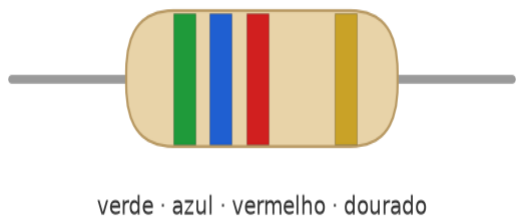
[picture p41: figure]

ScaraNode · Rev. v18 · 27/09/2026 | Projetista: Daniel M. Torres | 16 / 44

Resistor 47 kΩ

Qtd | Referências | Valor | Comprar
1 | R9 | 47k | Resistor 1/4 W 5%, furos a 10,16 mm
Faixas de cor | Modelo 3D (KiCad) | Onde fica

4 faixas (5%, corpo bege): amarelo, violeta, laranja, dourado. Em 5 faixas (1%, corpo geralmente azul): amarelo, violeta, preto, vermelho, marrom. Confira com o multímetro antes de soldar: marrom e vermelho se confundem com pouca luz. Parte de cima do divisor da 24 V.

Resistor 5,6 kΩ

Qtd | Referências | Valor | Comprar
1 | R10 | 5k6 | Resistor 1/4 W 5%, furos a 10,16 mm
Faixas de cor | Modelo 3D (KiCad) | Onde fica

4 faixas (5%, corpo bege): verde, azul, vermelho, dourado. Em 5 faixas (1%, corpo geralmente azul): verde, azul, preto, marrom, marrom. Confira com o multímetro antes de soldar: marrom e vermelho se confundem com pouca luz. Parte de baixo do divisor; fica embaixo do plugue USB.

ScaraNode · Rev. v18 · 27/09/2026 | Projetista: Daniel M. Torres | 17 / 44

Conector 24 V (J5)

Qtd | Referências | Valor | Comprar
1 | J5 | 24V | Conector plugável 2EDG 2 vias, passo 5,08 mm, macho 90° 2EDGRC na placa + plugue 2EDGK com parafusos
Modelo 3D (KiCad) | Onde fica

Plugue entra pela borda de cima (a frente do macho passa ~2,5 mm da borda, para o plugue não bater na placa). +24 V à esquerda, GND à direita. Pinos de 1 mm em furo de 1,6 mm.

Conector do motor (J6)

Qtd | Referências | Valor | Comprar
1 | J6 | MOTOR | Conector plugável 2EDG 4 vias, passo 5,08 mm, macho vertical 2EDGVC na placa + plugue 2EDGK com parafusos
Modelo 3D (KiCad) | Onde fica

Plugue encaixa por cima; a parede alta do macho fica para dentro da placa e o fio sai para a direita. De cima para baixo: 2B, 2A, 1A, 1B. Pinos de 1 mm em furo de 1,6 mm.

ScaraNode · Rev. v18 · 27/09/2026 | Projetista: Daniel M. Torres | 18 / 44

Conector DM556 (J4)

Qtd | Referências | Valor | Comprar
1 | J4 | DM556 | JST XH 4 vias 2,5 mm vertical (B4B-XH-A + fêmea XHP-4 + 4 terminais)
Foto (JST XH) | Modelo 3D (KiCad) | Onde fica

Da esquerda para a direita: 5V, PUL−, DIR−, ENA−. Encaixe o corpo no contorno da serigrafia.

Conectores NTC (J3, J8)

Qtd | Referências | Valor | Comprar
2 | J3 J8 | NTC1, NTC2 | JST XH 2 vias 2,5 mm vertical (B2B-XH-A + XHP-2 + 2 terminais)
Foto (JST XH) | Modelo 3D (KiCad) | Onde fica

Sinal à direita, GND à esquerda. O NTC não tem polaridade. J3 = motor do TMC2209, J8 = motor do DM556 (só com dois motores na placa).

ScaraNode · Rev. v18 · 27/09/2026 | Projetista: Daniel M. Torres | 19 / 44

Conectores dos fins de curso (J1, J2)

Qtd | Referências | Valor | Comprar
2 | J1 J2 | FIM1, FIM2 | JST XH 2 vias 2,5 mm vertical (B2B-XH-A + XHP-2 + 2 terminais)
Foto (JST XH) | Modelo 3D (KiCad) | Onde fica

Sinal à direita, GND à esquerda. A chave fecha o pino para o GND. O corpo do XH fica a ~0,9 mm da perna de R2/R3/R8.

Conectores das ventoinhas (J7, J9)

Qtd | Referências | Valor | Comprar
2 | J7 J9 | FAN 24V, FAN2 24V | JST XH 2 vias 2,5 mm vertical (B2B-XH-A + XHP-2 + 2 terminais)
Foto (JST XH) | Modelo 3D (KiCad) | Onde fica

+24 V à esquerda, GND à direita. As duas sempre ligadas: J7 na ventoinha do TMC2209, J9 na do DM556 ou da caixa.

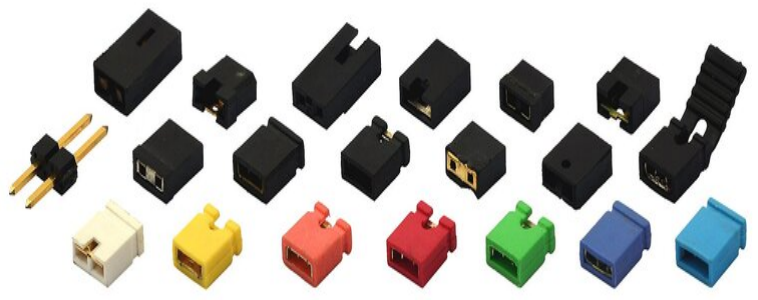
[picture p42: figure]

ScaraNode · Rev. v18 · 27/09/2026 | Projetista: Daniel M. Torres | 20 / 44

Header de UART (JU)

Qtd | Referências | Valor | Comprar
1 | JU | UART | Barra de pinos macho 1x2 2,54 mm + 1 jumper
Foto | Modelo 3D (KiCad) | Onde fica

Aberto na primeira ligação. Fechado = UART do TMC2209 no GP2, pelo pino 4 do soquete (ver capítulo 5).

Fixação (H1–H4)

Qtd | Referências | Valor | Comprar
4 | H1 H2 H3 H4 | M3 | Parafuso M3 + espaçador
Foto | Onde fica

Furos de 3,2 mm nos quatro cantos, num retângulo de 69 × 57 mm. Cabe cabeça M3 comum (~5,5 mm); com arruela, o H1 (ao lado do J7) e o H2 (ao lado do J5) ficam justos: use arruela só por baixo.

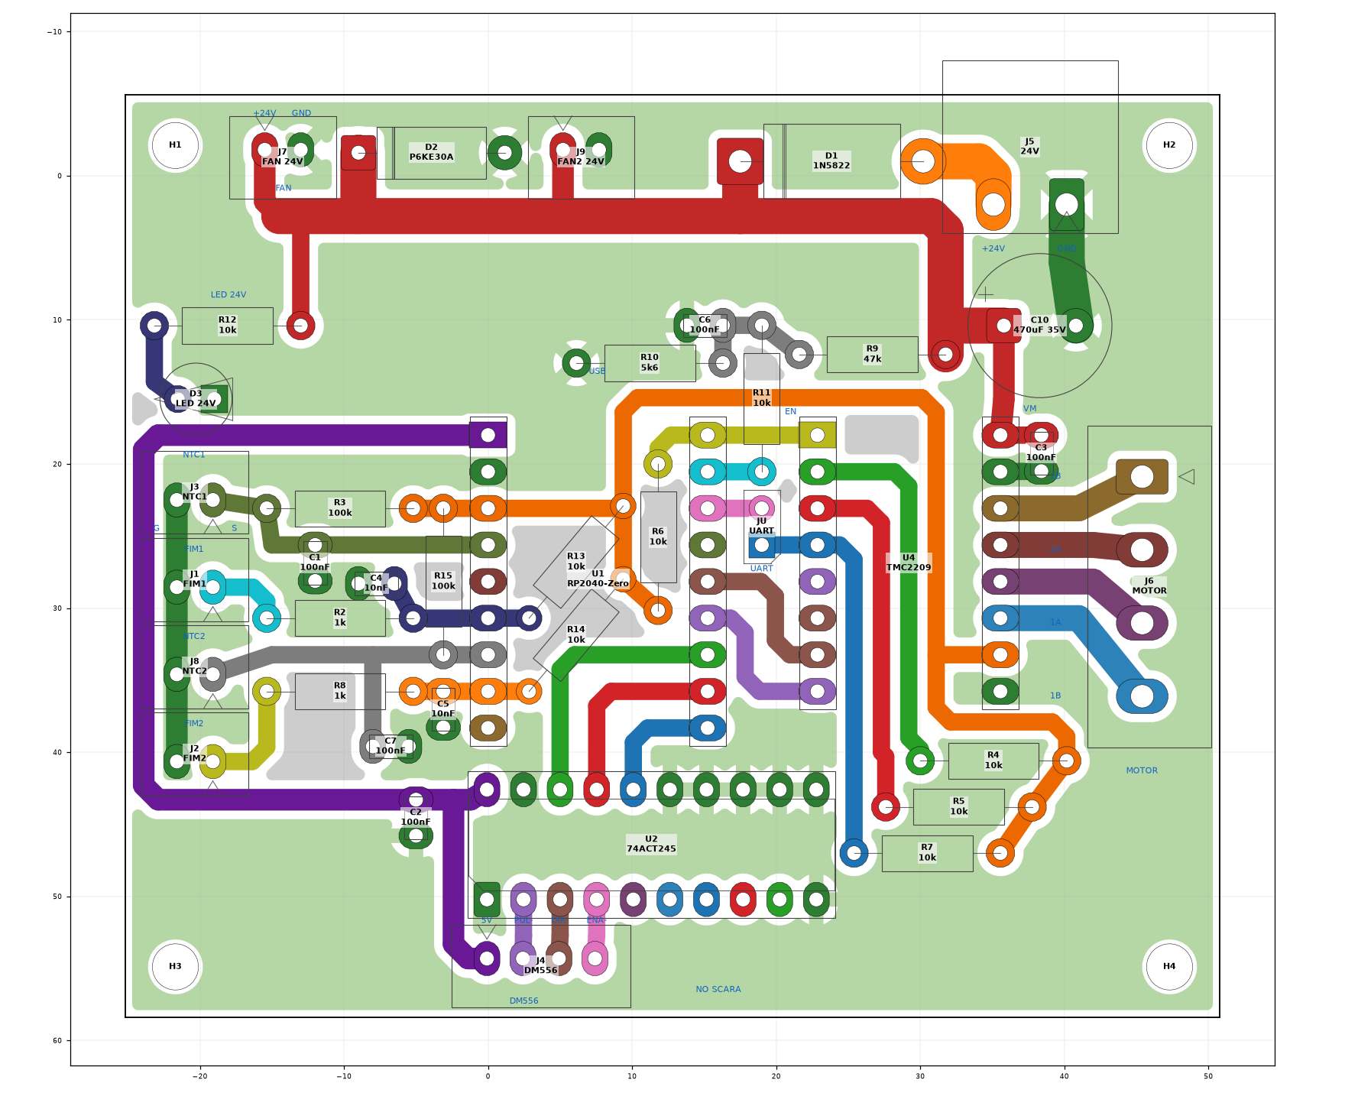
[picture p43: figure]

ScaraNode · Rev. v18 · 27/09/2026 | Projetista: Daniel M. Torres | 21 / 44

# 3. Fabricação (fresa CNC)

A placa é de face única: todo o cobre fica embaixo (B.Cu), e as peças vão do lado de cima, sem cobre. As regras foram escolhidas para uma fresa de desempenho desconhecido, então valem para praticamente qualquer CNC caseira.

## Regras do desenho

Regra | Valor
Isolação entre cobres (vão) | 0,60 mm em todo lugar (mínimo medido: 0,601 mm)
Trilhas | sinal 1,2 · 3,3 V 1,2 · 5 V 1,5 · motor 1,8 · 24 V e GND de potência 2,5 mm
Ilhas | soquetes e headers ovais 2,6 × 1,8 · resistores 2,0 · capacitores 1,8 × 2,4 · conectores 2EDG 2,4 × 3,6 · C10 2,4 mm
Anel de cobre em volta do furo | mínimo 0,40 mm em todos os furos
Cobre até a borda | 0,5 mm
Plano de GND | preenche o que sobra. Ilhas soltas ficam, porque sobra menos cobre para a fresa tirar. Alívio térmico em X nos pads de GND.

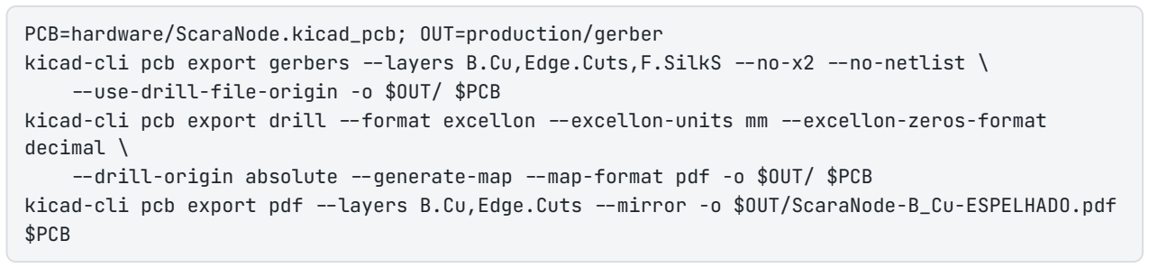
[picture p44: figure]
PCB=hardware/ScaraNode.kicad_pcb; OUT=production/gerber; -use-drill-file-origin -o $OUT/ $PCB; decimal \; $PCB

ScaraNode · Rev. v18 · 27/09/2026 | Projetista: Daniel M. Torres | 22 / 44

Face de cobre vista de cima (através da placa). Verde = GND ligado, cinza = ilha solta, cores = redes.

## Ferramentas

Etapa | Ferramenta | Observação
Isolação | V-bit 20–30° com ponta de 0,1–0,2 mm, ou fresa reta de 0,4–0,6 mm | Acima de 0,6 mm não passa entre ilhas vizinhas. Com 0,4 mm, faça 2 passadas.
Furos finos | broca 1,0 mm de metal duro | 118 furos: R, C, DIP, LED, D2, soquetes, JST XH, headers, C10
Furos grossos | broca 1,6 mm | 8 furos: D1 (2), conector J5 (2) e conector J6 (4)
Contorno e M3 | fresa reta de 1,5–2,0 mm | Contorno em 3–4 passadas. Os 4 furos de 3,2 mm saem com essa fresa (mill holes).

A placa usa só duas brocas. Os furos foram agrupados na v13, e as ilhas cresceram onde foi preciso para manter o anel de 0,4 mm.

Folgas: - A peça mais justa é a barra fêmea (pino de 0,64 mm quadrado em furo de 1,0 mm). Os furos precisam estar bem posicionados: fure uma fileira de 9 e teste a barra antes de fazer o resto. - A peça mais folgada é o conector 2EDG (pino de ~1,0 mm em furo de 1,6 mm). O corpo assenta na placa e a ilha oval de 2,4 × 3,6 mm segura.

## Arquivos de produção

Para mandar ao operador da CNC: production/cnc/ScaraNode-v18-CNC.zip . Tem um arquivo por ferramenta, com a operação e a ferramenta no nome (isolação, uma furação por broca, contorno), numerados na ordem da fresa, e um PDF com o resumo, as ferramentas, o aviso de espelhamento e a imagem de conferência.

Já gerados em production/gerber/ :

Arquivo | Conteúdo
ScaraNode-B_Cu.gbl | cobre (face única), visto por cima, através da placa
ScaraNode-Edge_Cuts.gm1 | contorno 76 × 64 mm
ScaraNode.drl | furação Excellon: mm, absoluto, decimal, mesma origem do Gerber
ScaraNode-drl_map.pdf | mapa de furos por diâmetro
ScaraNode-B_Cu-ESPELHADO.pdf / .png | cobre já espelhado: como a placa fica olhando o lado do cobre
ScaraNode-F_Silkscreen.gto | serigrafia do lado das peças (só para conferência, não fresa)

Para regerar depois de editar a placa no KiCad:

kicad-cli pcb export gerbers -layers B.Cu,Edge.Cuts,F.SilkS -no-x2 -no-netlist \

kicad-cli pcb export drill -format excellon -excellon-units mm -excellon-zeros-format

-drill-origin absolute -generate-map -map-format pdf -o $OUT/ $PCB
kicad-cli pcb export pdf -layers B.Cu,Edge.Cuts -mirror -o $OUT/ScaraNode-B_Cu-ESPELHADO.pdf

ScaraNode · Rev. v18 · 27/09/2026 | Projetista: Daniel M. Torres | 23 / 44

## Desenho mecânico

Placa 76 × 64 mm. Furos M3 de 3,2 mm, com centro a 3,5 mm das bordas. Origem no canto inferior esquerdo da vista de cima (Y para cima, como no CAD):

Furo | X (mm) | Y (mm) | Posição
H3 | 3,5 | 3,5 | inferior esquerdo
H4 | 72,5 | 3,5 | inferior direito
H1 | 3,5 | 60,5 | superior esquerdo
H2 | 72,5 | 60,5 | superior direito

Os quatro formam um retângulo de 69 × 57 mm entre centros (v18: até a v17 o H2 ficava 14,5 mm mais baixo, porque o borne J5 ocupava o canto).
DXF para a caixa ou o suporte: production/ScaraNode-mecanico.dxf (camadas CONTORNO , FUROS , CENTRO , COTAS ; mm).

## ⚠️ Espelhamento: o erro que inutiliza a placa

O Gerber da face de baixo é desenhado visto por cima. Se você fresa com o cobre virado para cima, o CAM (no FlatCAM: Mirror, eixo Y) tem que mostrar a placa igual à imagem abaixo:

conector de 24 V (J5) e conector do motor (J6) à esquerda
NTC e fins de curso à direita
USB do RP2040-Zero em cima

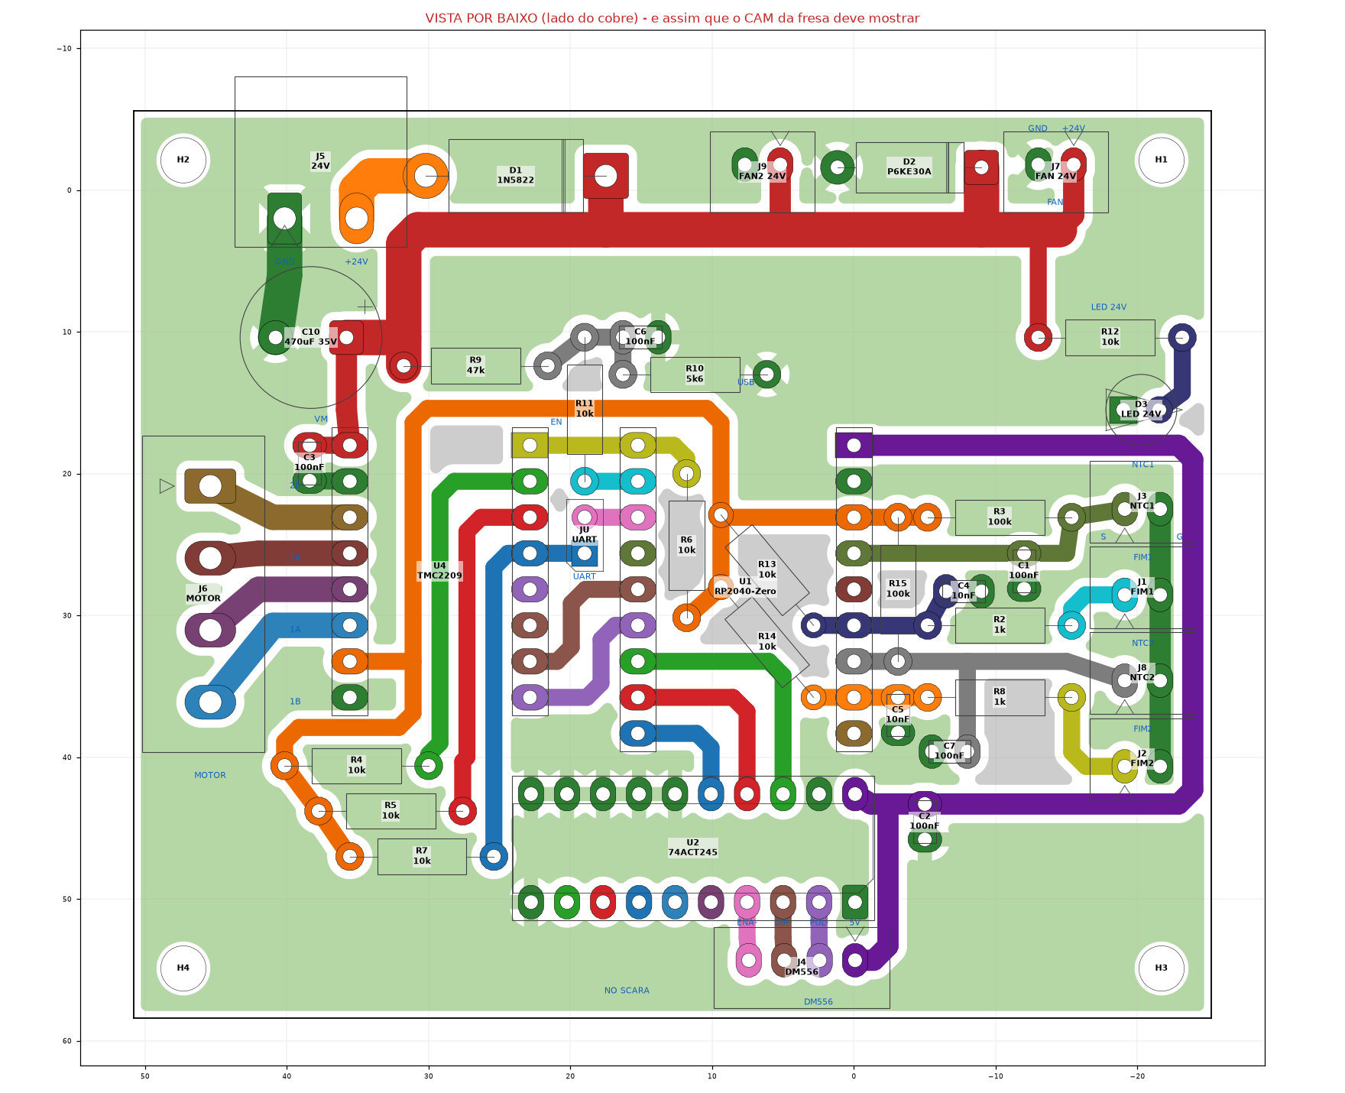
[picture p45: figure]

ScaraNode · Rev. v18 · 27/09/2026 | Projetista: Daniel M. Torres | 24 / 44

Se o CAM mostrar a placa igual à vista de cima, o espelhamento está errado e nenhum módulo vai encaixar.

## Conferência depois de fresar

1. Com o multímetro em continuidade, confira que nenhuma trilha vizinha está em curto, principalmente entre as fileiras dos soquetes e perto das ilhas de GND.
2. Encaixe a barra fêmea de 9 pinos nos furos do RP2040-Zero antes de soldar qualquer peça.
3. Compare a placa com a ScaraNode-B_Cu-ESPELHADO.png , olhando pelo lado do cobre.

ScaraNode · Rev. v18 · 27/09/2026 | Projetista: Daniel M. Torres | 25 / 44

# 4. Montagem

Peças do lado sem cobre, solda do lado do cobre. Monte da peça mais baixa para a mais alta: assim a placa apoia plana na bancada a cada etapa.

## Antes de começar

Placa fresada e conferida (capítulo 3).
Teste o encaixe: uma barra fêmea de 9 pinos nos furos do RP2040-Zero e o conector 2EDG nos furos de 1,6 mm.
Ferro de 30–60 W, estanho 0,8 mm com fluxo, alicate de corte rente.
Separe as peças pelo BOM e confira os valores dos resistores com o multímetro.

ScaraNode · Rev. v18 · 27/09/2026 | Projetista: Daniel M. Torres | 26 / 44

## Sequência

Passo | Peça | Onde | Cuidado
1 | R13, R14 (10k)

Ficam embaixo do RP2040-Zero: têm que entrar antes da barra fêmea. R13 e R14 inclinados 50°, paralelos; o corpo do R14 passa por cima da trilha STP.

2 | R6 (10k)

Também fica embaixo do RP. Aproveite e monte os outros 10k (R4, R5, R7, R11, R12).

3 | Demais resistores

R2, R8 (1k) · R3, R15 (100k) · R9 (47k) · R10 (5k6). Todos deitados, sem polaridade; o R15 fica na vertical, ao lado da barra fêmea da esquerda do RP.

4 | D1 1N5822 | ⚠️ Faixa do catodo para a esquerda (ilha quadrada).
5 | D2 P6KE30A | ⚠️ Faixa do catodo para a esquerda (ilha quadrada).
6 | Cerâmicos C1–C7 | Sem polaridade. 100 nF: C1, C2, C3, C6, C7 · 10 nF: C4, C5.
7 | Soquete DIP-20 do U2

Chanfro do soquete para a esquerda (lado do pino 1). Solde dois cantos, confira que assentou e depois o resto. O CI só entra no passo 14.

8

Barras fêmea do RP (2
× 1x9) e do TMC (2 ×
1x8)

Encaixe o módulo nas barras antes de soldar, para as fileiras ficarem paralelas. Solde as pontas, confira o prumo e depois o resto.

9 | JU (1x2) | Pinos curtos para baixo. Sem jumper por enquanto.
10 | LED D3 | Perna curta (catodo, lado chato) na ilha quadrada, à direita.

11

JST XH J1, J2, J3, J4,
J7, J8, J9

Corpo sobre o contorno da serigrafia. J1–J3 ficam a ~0,9 mm das pernas de R2/R3/R8.

12 | C10 470 µF | ⚠️ Perna longa (+) na ilha quadrada, à esquerda. Assente bem: fica a ~0,8 mm da cabeça do M3 do H2 e a ~1,2 mm do borne J5.

ScaraNode · Rev. v18 · 27/09/2026 | Projetista: Daniel M. Torres | 27 / 44
Passo | Peça | Onde | Cuidado

13

Conectores 2EDG J5 e
J6

J5 (24 V, macho 90°): a abertura para a borda de cima. J6 (motor, macho vertical): parede alta para dentro da placa, o fio do plugue sai para a direita. Confira com o plugue encaixado antes de soldar.

14 74ACT245 no soquete

Chanfro/ponto do pino 1 para a esquerda, igual ao soquete. Endireite as pernas na bancada antes.

15

Módulos (só depois da
conferência)

RP2040-Zero com USB para cima. TMC2209 com EN no canto EN e VM no canto VM.

## Alturas e interferências

Embaixo do plugue USB-C do RP só há peças deitadas (C6, R10, R11), com menos de 3 mm de altura. O RP2040-Zero fica a ~8,5 mm da placa, em cima da barra fêmea; R6, R13 e R14 ficam embaixo dele. C10 (Ø10 mm) fica a ~1,4 mm do corpo do J5: assente bem, sem inclinar.

## Polaridades: resumo

Peça | Marca na peça | Ilha quadrada | Lado
D1 1N5822 | faixa = catodo | catodo | esquerda
D2 P6KE30A | faixa = catodo | catodo | esquerda
D3 LED | lado chato / perna curta = catodo | catodo | direita
C10 | faixa (−); perna longa (+) | + | esquerda
U2 74ACT245 | chanfro / ponto = pino 1 | pino 1 (GND) | esquerda
RP2040-Zero | USB-C | — | para cima
TMC2209 | serigrafia EN / VM do módulo | — | EN ao lado do GP0

## Conferência antes de energizar

Sem módulos, sem jumpers e com o C10 descarregado:

Medida (multímetro) | Esperado
Continuidade +24 V × GND no J5 | não pode apitar (um bip curto é o C10 carregando)
5V × GND e 3V3 × GND no soquete do RP | não pode apitar
Pino EN do soquete do TMC × 3V3 | ~10 kΩ (R6)
GP27 × 3V3 e GP15 × 3V3 no soquete do RP | ~10 kΩ (R13, R14)
GND do J3/J1/J8/J2 × GND do J5 | continuidade
Pino 1 × pino 20 do soquete do U2 (GND × 5V) | não pode apitar

No módulo TMC2209, antes de fechar o JU: confirme com o multímetro ou na serigrafia que o pino 4 (posição do MS3) é o PDN_UART. A placa liga a UART nesse pino desde a v18.

Próximo passo: 8. Primeira ligação e testes.

ScaraNode · Rev. v18 · 27/09/2026 | Projetista: Daniel M. Torres | 28 / 44

# 5. Conectores, pinagem e jumpers

Todas as posições abaixo são na vista de cima (lado das peças, USB do RP para cima).

## Pinagem do RP2040-Zero

Coluna esquerda, de cima para baixo: 5V, GND, 3V3, GP29, GP28, GP27, GP26, GP15, GP14 . Coluna direita, de cima para baixo: GP0 … GP8 . Os pinos castelados de baixo (GP9–GP13) não são usados.

Pino | Rede | Função | No printer.cfg
5V | 5V | Vem do USB; alimenta o 74ACT245 e o PUL+/DIR+/ENA+ do DM556 | —
GND | GND | Terra comum (USB, 24 V, sensores) | —
3V3 | 3V3 | Regulador do módulo; alimenta o VDD do TMC, os pull-ups e o NTC | —
GP0 | EN | Enable do TMC2209 (ativo baixo, pull-up R6) | enable_pin: !gpio0
GP1 | VSENSE | Monitor da 24 V (~2,5 V com 24 V) | [gcode_button] pin: gpio1
GP2 | UART | PDN_UART do TMC2209 (pino 4 do soquete), via jumper JU | uart_pin: gpio2
GP4 | STP | STEP do TMC2209 | step_pin: gpio4
GP5 | DIR | DIR do TMC2209 | dir_pin: gpio5
GP6 | DM_STP | PUL do DM556 via 74ACT245 | step_pin: !gpio6
GP7 | DM_DIR | DIR do DM556 via 74ACT245 | dir_pin: gpio7
GP8 | ENA | ENA do DM556 via 74ACT245 (alto = habilitado) | enable_pin: gpio8
GP15 | SW2 | Fim de curso 2 (J2), pull-up 10k R14 | endstop_pin: !gpio15 (NA)
GP27 | SW1 | Fim de curso 1 (J1), pull-up 10k R13 | endstop_pin: !gpio27 (NA)
GP26 | NTC2 | ADC0, NTC2 (J8) com pull-up de 100k (R15) | sensor_pin: gpio26
GP29 | NTC | ADC3, NTC1 (J3) com pull-up de 100k (R3) | sensor_pin: gpio29
GP3, GP14, GP28 | livres | Sem trilha; acelerômetro I2C por fio (ver capítulo 6) | i2c_software_*

Dois canais independentes (v18): o TMC2209 (GP4/GP5/GP0) e o DM556 (GP6/GP7/GP8) têm STEP, DIR e enable próprios. Uma placa pode mover dois motores diferentes ao mesmo tempo, um em cada driver. Até a v17, o STEP e o DIR iam juntos para os dois.

## Conectores

Conector | Pino (vista de cima) | Liga em | Observação
J5 24 V (2EDG 90°, plugue pela borda de cima) | esquerda: +24 V | +24 V da fonte, por um fusível de 2 A só desta placa (ver capítulo 6) | Passa pelo D1; invertido, nada liga

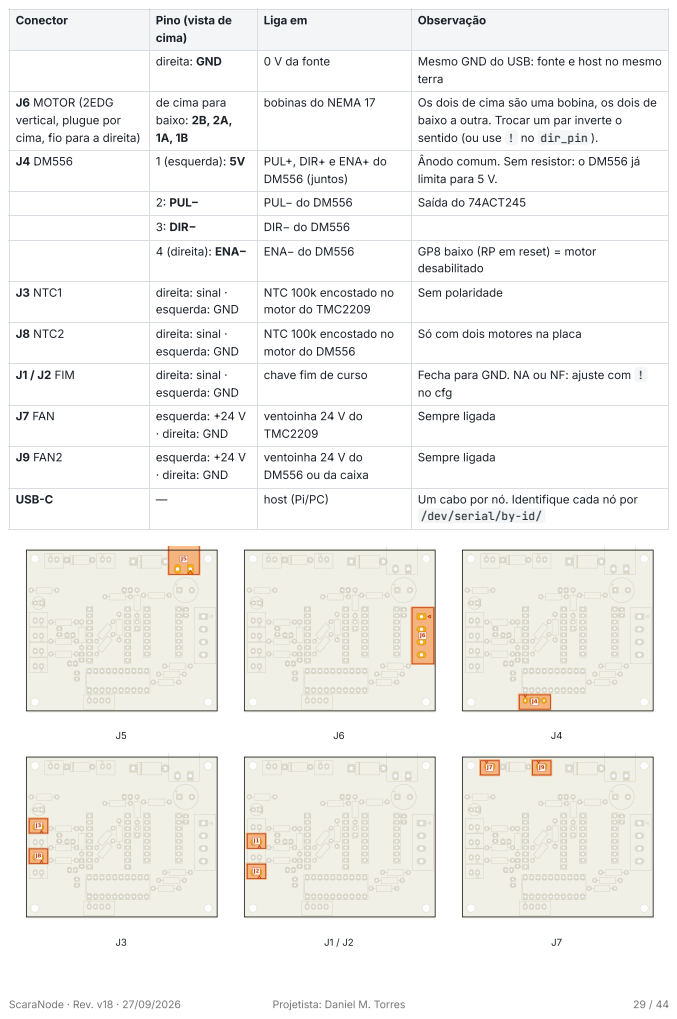
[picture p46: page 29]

Conector | Pino (vista de cima) | Liga em | Observação

direita: GND | 0 V da fonte | Mesmo GND do USB: fonte e host no mesmo terra

J6 MOTOR (2EDG vertical, plugue por cima, fio para a direita) | de cima para baixo: 2B, 2A, 1A, 1B | bobinas do NEMA 17 | Os dois de cima são uma bobina, os dois de baixo a outra. Trocar um par inverte o sentido (ou use ! no dir_pin ).

J4 DM556 | 1 (esquerda): 5V | PUL+, DIR+ e ENA+ do DM556 (juntos) | Ânodo comum. Sem resistor: o DM556 já limita para 5 V.

2: PUL− | PUL− do DM556 | Saída do 74ACT245
3: DIR− | DIR− do DM556
4 (direita): ENA− | ENA− do DM556 | GP8 baixo (RP em reset) = motor desabilitado

J3 NTC1 | direita: sinal · esquerda: GND | NTC 100k encostado no motor do TMC2209 | Sem polaridade

J8 NTC2 | direita: sinal · esquerda: GND | NTC 100k encostado no motor do DM556 | Só com dois motores na placa

J1 / J2 FIM | direita: sinal · esquerda: GND | chave fim de curso | Fecha para GND. NA ou NF: ajuste com ! no cfg

J7 FAN | esquerda: +24 V · direita: GND | ventoinha 24 V do TMC2209 | Sempre ligada

J9 FAN2 | esquerda: +24 V · direita: GND | ventoinha 24 V do DM556 ou da caixa | Sempre ligada

USB-C | — | host (Pi/PC) | Um cabo por nó. Identifique cada nó por /dev/serial/by-id/

ScaraNode · Rev. v18 · 27/09/2026 | Projetista: Daniel M. Torres | 30 / 44

## Pinagem do soquete StepStick (U4)

Pino | Função | Liga em | Pino | Função | Liga em
1 | EN | GP0 + R6 (pull-up) | 16 | VMOT | 24 V (após D1) + C3
2 | MS1 | R4 (pull-up) | 15 | GND | GND de potência
3 | MS2 | R5 (pull-up) | 14 | 2B | J6
4 | PDN_UART | JU → GP2, pull-up R7 | 13 | 2A | J6
5 | — | livre | 12 | 1A | J6
6 | CLK | livre (clock interno) | 11 | 1B | J6
7 | STEP | GP4 | 10 | VDD | 3V3
8 | DIR | GP5 | 9 | GND | GND

O pino 6 fica livre de propósito: aterrar sem medir pode danificar módulos que usam esse pino para outra coisa. A4988 e DRV8825 só funcionam com o curto RST–SLP feito no próprio módulo (os pinos 5 e 6 da placa não estão mais livres para isso).

## Jumpers

MS1 e MS2 fixos (sem jumper desde a v18)

MS1 e MS2 ficam em 3,3 V pelos pull-ups R4 e R5. Até a v17 havia o jumper ZM para aterrá-los; ele saiu porque:

Com a UART (o uso normal), o Klipper tira o micropasso dos pinos ( mstep_reg_select ) e usa o microsteps do cfg. MS1 e MS2 só dão o endereço da UART: os dois em 1 = endereço 3
( uart_address: 3 ). Com um driver por RP, o endereço só precisa bater com o cfg.
Em standalone (JU aberto), o TMC2209 fica em 1/16 ( microsteps: 16 ).

Pino 4 (posição do MS3): nos módulos TMC2209 comuns, é o PDN_UART. Na v18 ele vai ao JU e tem o R7 (10k) como pull-up. Até a v17 a UART ia ao pino 5, que no módulo usado não é a UART. Módulos com a UART no pino 5 (ex.: Watterott SilentStepStick, que tem o SPREAD no pino 4) não servem nesta placa.

JU — UART do TMC2209

Aberto: driver em standalone. Corrente pelo trimpot, micropasso fixo em 1/16.
Fechado: GP2 ligado ao PDN_UART (pino 4 do StepStick). Com a seção [tmc2209] no cfg, o trimpot é ignorado, o micropasso vem do cfg, e MS1/MS2 (fixos em 1) dão o endereço 3. Sem a seção no cfg, o driver continua em standalone mesmo com o JU fechado.
UART de 1 fio (half-duplex), sem resistor em série: o Klipper alterna a direção do GP2. O R7 só segura o nível alto com o JU aberto.

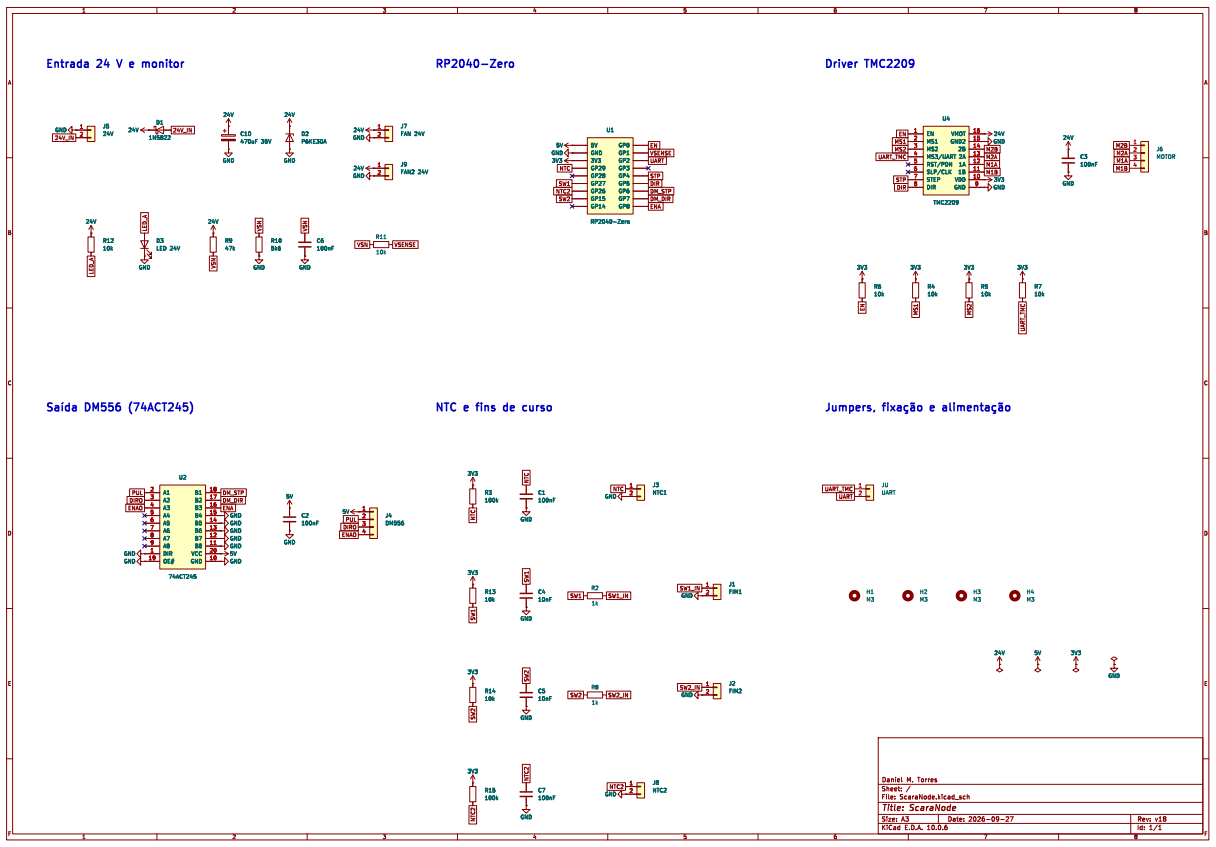
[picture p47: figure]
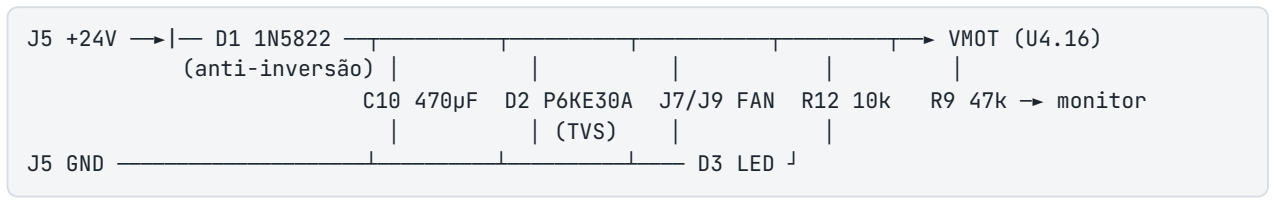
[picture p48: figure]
(anti-inversão) │; │ (TVS)

ScaraNode · Rev. v18 · 27/09/2026 | Projetista: Daniel M. Torres | 31 / 44

# 6. Circuitos e cálculos

O esquema completo está em hardware/ScaraNode.kicad_sch (KiCad 10) e em PDF, folha A3. Ele é desenhado por blocos, com rótulos na ponta de cada pino no lugar de fios: pinos com o mesmo rótulo estão ligados.

Na v18 a placa confere com o esquemático: 124 pinos, ERC sem erro nem aviso e paridade placa × esquemático sem divergência (valor, footprint e rede de cada pino). Esquemático e conferência da placa saem da mesma descrição do circuito: o ERC e a paridade conferem tipos de pino e a placa, não a concepção do circuito. Os trechos abaixo seguem esse esquema.

## Entrada 24 V

J5 +24V ──►|── D1 1N5822 ──┬──────────┬──────────┬───────────┬─────────┬──► VMOT (U4.16)

C10 470µF D2 P6KE30A J7/J9 FAN R12 10k R9 47k ─► monitor

J5 GND ─────────────────────┴──────────┴──────────┴──── D3 LED ┘

O +24 V desce pelo R9 até o C10 e só então vai ao VM do TMC (v18): o C10 fica no caminho do driver. O retorno de GND do conector vai por uma trilha própria de 2,5 mm até o C10, e dali ao pino 15 do TMC. É o caminho dos pulsos do chopper (até ~1 A), que não deve depender dos raios finos do alívio térmico do plano.

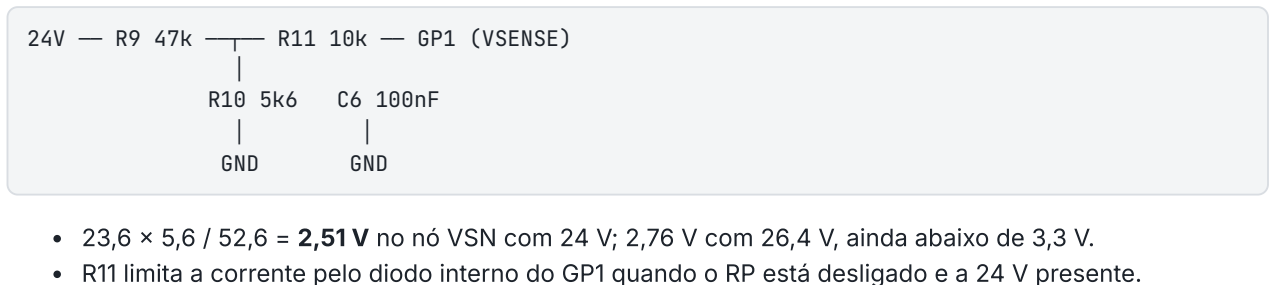
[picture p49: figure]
GND

ScaraNode · Rev. v18 · 27/09/2026 | Projetista: Daniel M. Torres | 32 / 44
Grandeza | Valor | Comentário
VM no TMC | 23,6 V | 24 V menos ~0,45 V do D1. O TMC2209 aceita de 4,75 a 29 V.
Frenagem | ~0,04 J (estimativa: J2, 24:1, 250 mm/s) | O D1 impede a energia de voltar para a fonte. Com 470 µF, o VM sobe a ~27,4 V; com 100 µF chegava a ~30 V.
TVS P6KE30A | trabalha até 25,6 V, conduz a partir de 28,5 V | Segura surtos; não é proteção fina para o driver
LED | (23,6 − 2) / 10k ≈ 2,2 mA | Visível. R12 = 4k7 dá ~4,6 mA
Ventoinhas (J7, J9) | 24 V direto, sempre ligadas | J7 no TMC2209, J9 no DM556 ou na caixa. Brushless não precisa de diodo. Sempre ligadas de propósito: uma ventoinha controlada por firmware pode ficar parada com o driver trabalhando

## Fusíveis (fora da placa)

A placa não tem fusível: a proteção fica numa caixa de fusíveis de lâmina automotiva (6 ou 8 vias, de autopeças), com um fusível por circuito. Até a v17 havia um fusível só para a máquina toda. Como ele é dimensionado para a soma de tudo, inclusive os DM556, não abriu quando um TMC2209 entrou em curto e pegou fogo (27/09/2026).

Circuito | Fusível de lâmina (padrão ATO ou mini, 32 V DC)
Cada ScaraNode (TMC2209 + ventoinhas J7/J9) | 2 A
Cada DM556 com NEMA 23 a 4,2 A | 5 A

Um fio por circuito, saindo da caixa. Duas placas no mesmo fusível voltam ao problema original.
Por que 2 A: pela placa passam só o TMC2209 e as ventoinhas. O driver converte 24 V com pouca corrente em poucos volts com mais corrente na bobina, então a fonte fornece só a potência gasta: bobinas (~4 W a 1,2 A), perdas do driver (~1 W), trabalho mecânico (até ~9 W) e ventoinhas (~7 W) dão ~0,9 A no pior caso e ~0,5 A parado. O fusível trabalha abaixo de 75% do valor e abre em milissegundos num curto (dezenas de ampères).
Por que o DM556 puxa menos que 4,2 A da fonte: pelo mesmo motivo; 5 A é folga para as acelerações. Tensão do fusível: pelo menos 32 V DC. É o padrão dos fusíveis de lâmina. Em DC a corrente não passa por zero e o fusível precisa apagar o arco sozinho; um fusível marcado só "250 V AC" não garante isso. Pico ao ligar: o C10 (470 µF) carrega com um pico de milissegundos (~0,5 A²s), bem abaixo do que funde um fusível de lâmina de 2 A.
Para conferir o consumo real: multímetro em série no +24 V de uma placa (escala de 10 A DC), com a máquina no movimento mais pesado. Se passar de 1,5 A, suba para 3 A.
Fusível aberto: procure o curto antes de trocar (driver, TVS D2, C10, motor).

## Monitor da 24 V

24V ── R9 47k ──┬── R11 10k ── GP1 (VSENSE)

23,6 × 5,6 / 52,6 = 2,51 V no nó VSN com 24 V; 2,76 V com 26,4 V, ainda abaixo de 3,3 V. R11 limita a corrente pelo diodo interno do GP1 quando o RP está desligado e a 24 V presente.

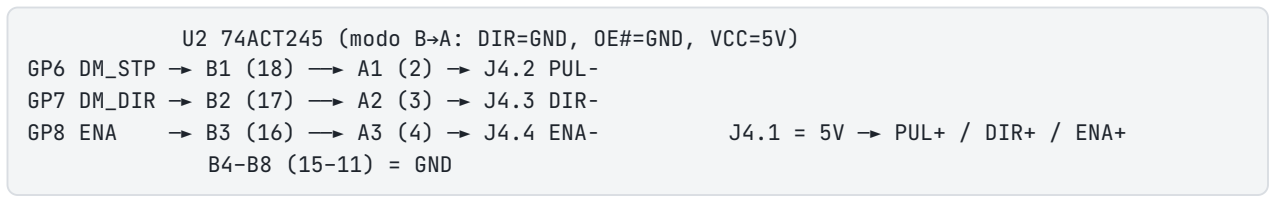
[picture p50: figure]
B4–B8 (15–11) = GND

ScaraNode · Rev. v18 · 27/09/2026 | Projetista: Daniel M. Torres | 33 / 44

Abaixo do limiar de nível alto do RP2040, o botão "solta" e o Klipper executa o release_gcode (M112).

## Driver TMC2209

VDD do módulo em 3,3 V (VCC_IO). EN com pull-up de 10k (R6): sem firmware rodando, o driver fica desligado.
STEP e DIR chegam direto do RP (GP4, GP5), separados dos do DM556.
MS1/MS2 fixos em 1 pelos pull-ups de 10k (R4, R5): endereço UART 3; em standalone, 1/16.
Pino 4 (PDN_UART) chega ao GP2 pelo JU, com pull-up de 10k (R7). Pinos 5 e 6 (CLK) ficam abertos = clock interno.
Módulo com RSENSE de 0,11 Ω: no cfg, sense_resistor: 0.110 .
Corrente prática em StepStick: 1,0 a 1,2 A RMS, com ventoinha. Acima disso o driver desarma por temperatura. Para 1,7 A, use driver externo pelo J4.

## Saída para driver externo (74ACT245)

U2 74ACT245 (modo B→A: DIR=GND, OE =GND, VCC=5V) GP6 DM_STP ─► B1 (18) ──► A1 (2) ─► J4.2 PUL−
GP7 DM_DIR ─► B2 (17) ──► A2 (3) ─► J4.3 DIR−
GP8 ENA | ─► B3 (16) ──► A3 (4) ─► J4.4 ENA− | J4.1 = 5V ─► PUL+ / DIR+ / ENA+

Entradas TTL do ACT (nível alto ≥ 2,0 V) aceitam os 3,3 V do RP.
Com PUL+/DIR+/ENA+ em 5 V, a saída em nível baixo acende o opto do DM556 (~14 mA; o 245 aguenta 24 mA por saída).
Pulso de STEP ativo baixo: step_pin: !gpio6 e step_pulse_duration: 0.000005 (o DM556 pede 2,5 µs).
ENA: GP8 alto → A3 alto → opto apagado → motor habilitado ( enable_pin: gpio8 , sem ! ). Com o RP em reset ou em boot, o GP8 fica baixo e o DM556 fica desabilitado até o Klipper assumir.
O DM556 é opticamente isolado, então não se forma laço de terra.

## NTC

3V3 ── R3 100k ──┬── GP29 (ADC3) | NTC2: R15, C7, J8, GP26 (ADC0)

100k a 25 °C com pull-up de 100k dá 1,65 V; a 70 °C (~17,6k) dá ~0,49 V. O C1 filtra o ruído do cabo. Desde a v18 há duas entradas iguais: com dois motores na placa, uma em cada motor. O NTC fica no motor, não no driver: o TMC2209 se desliga sozinho por temperatura (e o Klipper avisa), e o DM556 tem as próprias proteções.

## Fins de curso

3V3 ── R13 10k ──┬── GP27 | (FIM2: R14, R8, C5, GP15)

Pull-up externo de 10k no lado do RP, 1k em série e 10 nF (RC de ~10 µs). Com a chave fechada, o pino fica em 3,3 × 1/11 ≈ 0,30 V. Por causa dos pull-ups externos (v14), o ^ no cfg é opcional.

ScaraNode · Rev. v18 · 27/09/2026 | Projetista: Daniel M. Torres | 34 / 44

## Pinos livres do RP2040

GP3, GP14 e GP28 não têm trilha. Com o GP26 no NTC2 (v18), sobram GP3, GP14 e GP28. O ADXL345 no Klipper só funciona por SPI (4 fios) e não cabe; use um acelerômetro I2C (MPU-6050/9250 ou LIS2DW, 2 fios, i2c_software_* no GP3/GP14) ou um acelerômetro USB à parte. Há um exemplo comentado em firmware/klipper/scaranode.cfg .

## Esquemático

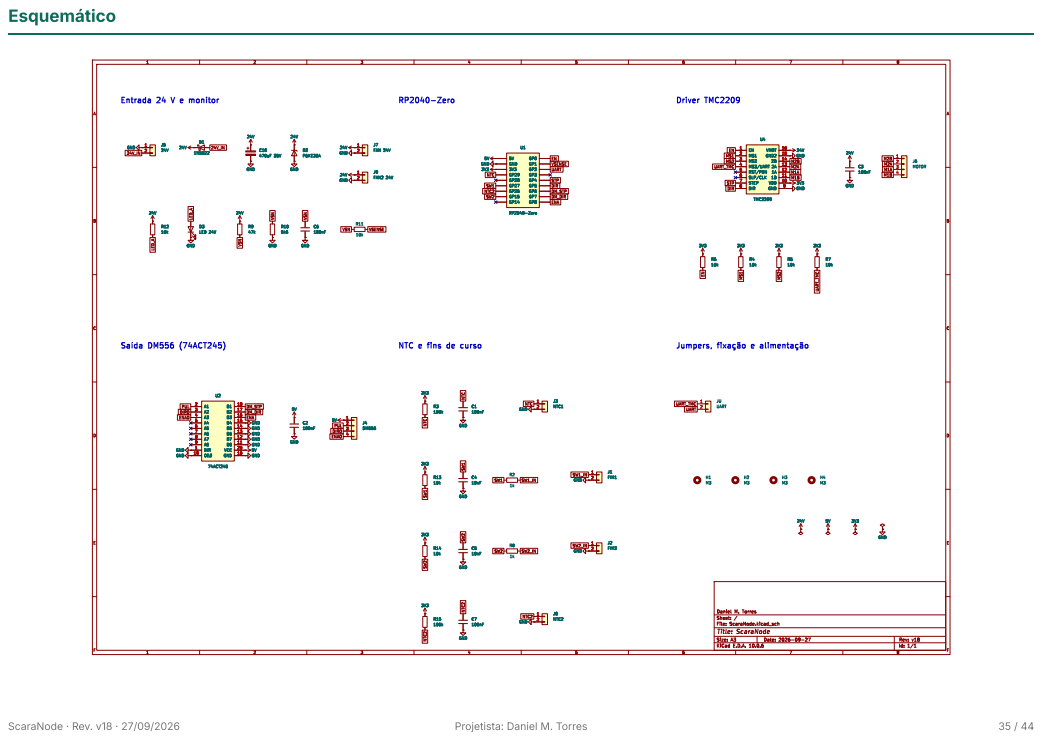
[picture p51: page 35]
ScaraNode · Rev. v18 · 27/09/2026; Projetista: Daniel M. Torres

ScaraNode · Rev. v18 · 27/09/2026 | Projetista: Daniel M. Torres | 36 / 44

# 7. Firmware Klipper

Cada nó é um micro-controlador ( [mcu <nome ] ) do Klipper. O host fala com os quatro pelo USB, e os pinos de cada nó levam o prefixo do nome ( j2:gpio4 ).

Desde a v18 os dois drivers têm pinos próprios: um nó pode mover um motor no TMC2209 e outro no DM556 ao mesmo tempo. Nesse caso, use o FIM1 ( gpio27 ) para o eixo do TMC e o FIM2 ( gpio15 ) para o do DM556: cada chave fica no mesmo MCU que o seu motor, o que é o melhor para o homing.

## Gravar o Klipper no RP2040-Zero

No host, na pasta do Klipper:

# Processor model: rp2040 · interface de comunicação: USB (padrão)

Primeira gravação: segure o botão BOOT do RP2040-Zero e conecte o USB. Ele aparece como um disco ( RPI-RP2 ): copie o out/klipper.uf2 para lá, ou grave pelo host:

make flash FLASH_DEVICE=2e8a:0003 # RP2040 em modo BOOT (Klipper atual)

Nas atualizações seguintes, com o nó já rodando o Klipper, FLASH_DEVICE pode ser o caminho /dev/serial/by-id/ . do nó.

Grave um nó por vez e anote o serial de cada um:

ls /dev/serial/by-id/
# usb-Klipper_rp2040_E6625C05E7xxxxxx-if00 ← cole no [mcu j2] serial:

Dica: etiquete cada placa (J1, J2, Z, J3) junto com o final do serial.

## Configuração

Referência completa, comentada: firmware/klipper/scaranode.cfg . Ela saiu da placa (pinagem conferida pino a pino), não do printer.cfg da máquina. O que depende da mecânica e da cinemática SCARA está marcado com # AJUSTAR .

ScaraNode · Rev. v18 · 27/09/2026 | Projetista: Daniel M. Torres | 37 / 44

Nó com TMC2209 (NEMA 17)

[mcu j2]
serial: /dev/serial/by-id/usb-Klipper_rp2040_XXXX-if00

[stepper_j2]
step_pin: j2:gpio4
dir_pin: j2:gpio5
enable_pin: !j2:gpio0 | # EN ativo baixo
microsteps: 16 | # com UART vem daqui; em standalone é fixo em 1/16
gear_ratio: 6:1, 4:1
endstop_pin: !j2:gpio27 | # chave NA para GND

[temperature_sensor motor_j2]
sensor_type: Generic 3950
sensor_pin: j2:gpio29
pullup_resistor: 100000
max_temp: 70

[gcode_button vm_sense_j2] pin: j2:gpio1
press_gcode:
G4 P0
release_gcode:
M112

Com o JU fechado (recomendado), acrescente:

[tmc2209 stepper_j2]
uart_pin: j2:gpio2 | # PDN_UART no pino 4 do soquete (v18)
uart_address: 3 | # MS1 e MS2 fixos em 1 (R4/R5)
run_current: 1.0 | # MÁXIMO 1,2 no StepStick
sense_resistor: 0.110
stealthchop_threshold: 0

⚠️ Para não queimar o driver

Um TMC2209 pegou fogo depois de rodar muito tempo a 1,7 A (27/09/2026). O que evita isso:

1. run_current no máximo 1,0–1,2 A no TMC2209. O StepStick não dissipa mais que isso, mesmo com ventoinha. O Klipper não impede um valor maior: o limite é seu. Motor que precisa de mais corrente vai no DM556.
2. Use a UART. Só com ela o Klipper lê os avisos de temperatura do TMC2209 (pré-aviso a ~120 °C, desligamento a ~143 °C) e para a máquina com erro. Em standalone, ninguém vigia o driver.
3. Nunca ligue nem desligue o cabo do motor com a 24 V ligada. A bobina gera um pico que mata o driver na hora, e nenhum componente da placa impede.
4. Ponteira (terminal tubular) nos fios dos plugues do motor (J6) e da 24 V (J5), bem apertados, e o plugue encaixado até o fim. Contato frouxo faz faísca.
5. Fusível de 2 A só para esta placa na caixa de fusíveis (capítulo 6).
6. Ventoinha no J7 sempre ligada, soprando o módulo.

## Tabela rápida de sinais

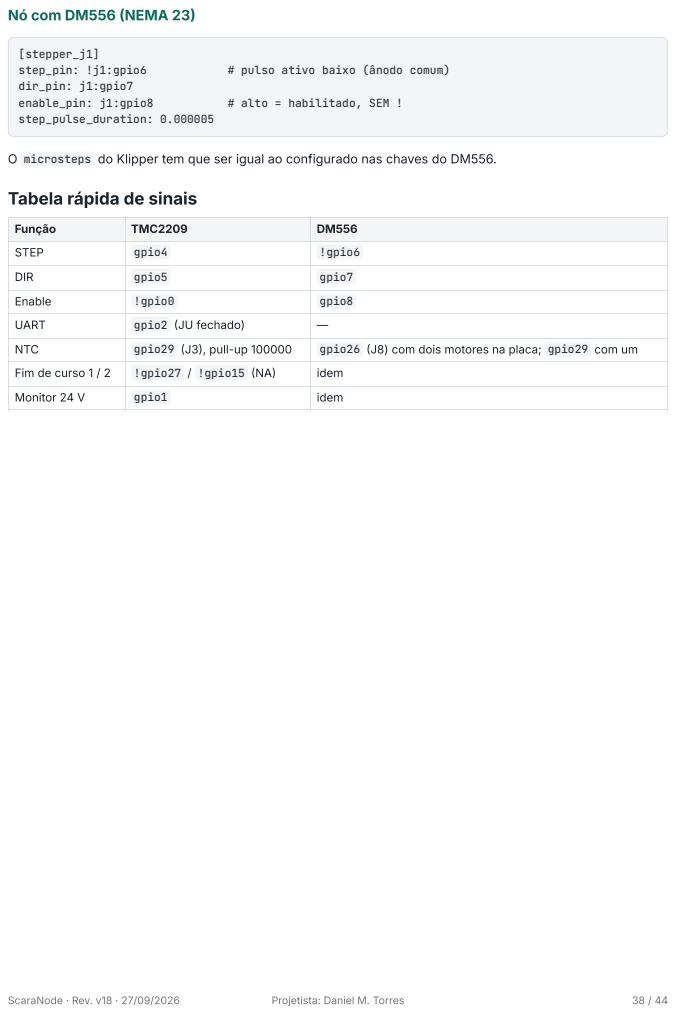
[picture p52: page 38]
ScaraNode · Rev. v18 · 27/09/2026; Projetista: Daniel M. Torres; [stepper_j1]; step_pin: !j1:gpio6; # pulso ativo baixo (ânodo comum); dir_pin: j1:gpio7; enable_pin: j1:gpio8; # alto = habilitado, SEM !; step_pulse_duration: 0.000005

Nó com DM556 (NEMA 23)

O microsteps do Klipper tem que ser igual ao configurado nas chaves do DM556.

Função | TMC2209 | DM556
STEP | gpio4 | !gpio6
DIR | gpio5 | gpio7
Enable | !gpio0 | gpio8
UART | gpio2 (JU fechado) | —
NTC | gpio29 (J3), pull-up 100000 | gpio26 (J8) com dois motores na placa; gpio29 com um
Fim de curso 1 / 2 | !gpio27 / !gpio15 (NA) | idem
Monitor 24 V | gpio1 | idem

ScaraNode · Rev. v18 · 27/09/2026 | Projetista: Daniel M. Torres | 39 / 44

# 8. Primeira ligação e testes

Faça na ordem. Cada passo só começa se o anterior deu o resultado esperado. Antes de tudo, faça a conferência sem energia e leia os cuidados para não queimar o driver no capítulo 7: corrente máxima, UART, nunca mexer no cabo do motor com a 24 V ligada.

## Roteiro

Passo | O que fazer | O que esperar
1 | Só o USB, sem 24 V, sem o módulo TMC | O LED do RP acende. Grave o Klipper (cap. 7); o nó aparece em /dev/serial/by-id/ .
2 | Meça o pino VDD do soquete do TMC e o pino 20 do U2 | 3,3 V e 5,0 V
3 | Ligue a 24 V, ainda sem o módulo | D3 acende. ~23,6 V no VMOT do soquete e ~2,5 V no GP1.
4 | Desligue tudo. Encaixe o TMC, ajuste o trimpot para ~1 A, religue o USB e depois a 24 V | Nada esquenta em repouso
5 | STEPPER_BUZZ STEPPER=stepper_j2 | O motor vibra 1 mm para um lado e para o outro. Se não vibrar, confira o EN e as bobinas no J6.
6 | Um G1 curto, depois um quadrado lento | Lados retos e tamanho certo. Curvo ou errado: confira gear_ratio , micropasso ou dir_pin .
7 | QUERY_ENDSTOPS com a chave solta e apertada | open → TRIGGERED . Se inverter, troque o ! do endstop_pin .
8 | Leia a temperatura do motor_j2 | Temperatura ambiente (±3 °C). Muito alta ou muito baixa: confira o pullup_resistor: 100000 .
9 | Nó DM556: mesmo roteiro | Se perder posição a cada inversão, tire o ! do step_pin . Motor sem torque: confira o ENA ( gpio8 , sem ! ).
10 | Corte a 24 V com o Klipper rodando | O Klipper entra em M112 ( release_gcode do vm_sense ). FIRMWARE_RESTART para voltar.
11 | Feche o JU e ative a seção [tmc2209] | DUMP_TMC STEPPER=stepper_j2 responde; o trimpot passa a ser ignorado.

## Diagnóstico

Sintoma | Causa provável | Onde olhar
Nada liga com 24 V, D3 apagado | Fusível da placa aberto (caixa central), 24 V invertido (o D1 bloqueia) ou D1 soldado ao contrário | Fusível na caixa (se abriu, procure o curto antes de trocar); polaridade do J5; faixa do D1 à esquerda
Fonte entra em proteção ao ligar a 24 V | D2 (TVS) soldado ao contrário | Faixa do D2 à esquerda
Klipper não acha o nó | Cabo USB só de carga, ou firmware não gravado | lsusb , ls /dev/serial/by-id/
Motor não segura (TMC) | EN em alto: Klipper não habilitou, ou R6 em curto | enable_pin: !gpio0

ScaraNode · Rev. v18 · 27/09/2026 | Projetista: Daniel M. Torres | 40 / 44
Sintoma | Causa provável | Onde olhar
Motor vibra mas não gira | Um par de bobinas trocado no J6 | Meça a resistência: pares de ~1–3 Ω
Motor gira ao contrário | Sentido da bobina | ! no dir_pin ou inverta um par
Fim de curso sempre acionado | Chave NF sem ! ajustado, ou pino de GND do conector sem solda | Continuidade GND J1 × J5
NTC marca −273 °C ou valor absurdo | NTC aberto, pino de GND do J3/J8 sem solda, ou pullup_resistor errado | J3/J8; continuidade GND J3 × J5
TMC desarma depois de minutos | Corrente acima de ~1,2 A RMS ou sem ventoinha | Trimpot / run_current , J7
DUMP_TMC sem resposta | JU aberto, ou o pino 4 do módulo não é o PDN_UART | Jumpers
DM556 não se move | J4 invertido, ou ENA desabilitando | Ordem 5V, PUL−, DIR−, ENA−; enable_pin: gpio8
M112 aleatório | Queda da 24 V, ou mau contato no J5 | Plugue do J5 encaixado e parafusos apertados; fonte

## O que a placa não faz

Entrada de 5 V separada. A lógica é alimentada pelo USB, que precisa estar ligado de qualquer jeito (é o canal de dados do Klipper). Um borne de 5 V extra só criaria o risco de alimentar a porta USB do host por trás.
Homing sem sensor (StallGuard). Precisa do pino DIAG do TMC2209, que o módulo StepStick usado não expõe. Além disso, o StallGuard atrás de planetária 6:1 + correia 4:1 é pouco confiável. O homing é por chave, no J1/J2.
Corrente acima de 1,2 A RMS no soquete. O StepStick não dissipa. Use driver externo pelo J4. Encoder ou realimentação de posição. O sistema é malha aberta, como todo Klipper.
Drivers SPI (TMC2130, TMC5160). Os pinos 2 e 3 do soquete estão nos pull-ups de MS1/MS2 e o 4 na UART, sem SPI.
Conector para acelerômetro. Não há. Para input shaping, sobram GP3, GP14 e GP28. O ADXL345 no Klipper só funciona por SPI (4 fios) e não cabe; use um acelerômetro I2C (MPU-6050/9250 ou LIS2DW, 2 fios, i2c_software_* no GP3/GP14) ou um acelerômetro USB à parte (exemplo no cfg).

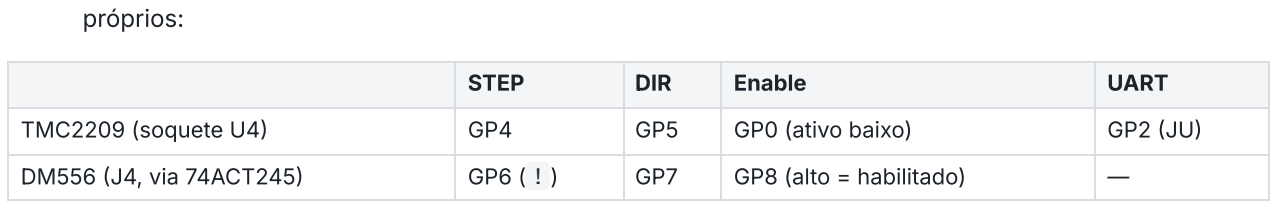
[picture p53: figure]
próprios:; STEP; DIR; Enable; UART; TMC2209 (soquete U4); GP0 (ativo baixo); DM556 (J4, via 74ACT245); GP8 (alto = habilitado)

ScaraNode · Rev. v18 · 27/09/2026 | Projetista: Daniel M. Torres | 41 / 44

# Histórico de revisões

Projetista: Daniel M. Torres.

Rev. | Data | Resumo
v18 | 27/09/2026 | Um canal por driver: TMC2209 no GP4/GP5 e DM556 no GP6/GP7, independentes; UART do TMC2209 no pino 4 do soquete (GP2); sem o jumper ZM (MS1/MS2 fixos, endereço 3); segundo NTC (J8, GP26); segunda ventoinha (J9); conectores plugáveis 2EDG no J5/J6; furos M3 esquadrados; fusível de 2 A por placa na caixa central; nenhuma curva de trilha de 90°
v17 | 25/09/2026 | Esquemático KiCad publicado (ERC e paridade com a placa); 13 resistores iguais de 1/4 W; R13 e R14 inclinados a 50° com o GND do RP ligado direto ao plano; coluna da esquerda com folgas iguais; GND contínuo sem o jumper de fio JP1; faixas de cor nos renders
v16 | 25/09/2026 | Placa 76 × 64 mm com furos M3 alinhados + DXF mecânico; U2 em soquete DIP-20; borne do motor KF128 azul; NTC separado dos fins de curso; LED de 5 mm
v15 | 25/09/2026 | Conectores de sinal passam a JST XH 2,5 mm (as peças reais); 74ACT245 soldado direto; borne da 24 V verde e do motor azul
v14 | 25/09/2026 | ENA do DM556 no GP8 (J4 passa a 4 vias); pull-ups de 10k R13/R14 nos fins de curso. Manual e repositório publicados.
v13 | 25/09/2026 | Só duas brocas (1,0 e 1,6 mm) + M3
v12 | 25/09/2026 | C10 = 470 µF 35 V; placa passa a 75,8 × 64 mm
v11 | 24/09/2026 | Jumper JU: UART do TMC2209 no GP5
v10 | 24/09/2026 | LED D3 na borda; trilha de retorno de GND do borne
v9 | 24/09/2026 | Anel dos conectores KK corrigido (0,40 mm); primeiros Gerbers
v1– v8 | 24/09/2026 | Layout inicial, regras de fresa, pinagem do RP2040

## v18 — canais independentes, UART no pino 4 e trilhas sem curva de 90°

Um canal por driver. Até a v17, o GP6/GP7 ia ao TMC2209 e ao 74ACT245 ao mesmo tempo: com os dois drivers ligados, os motores faziam o mesmo movimento. Agora cada driver tem STEP, DIR e enable

Uma placa pode mover dois motores diferentes ao mesmo tempo. O DM556 fica com as trilhas da v17 até o
245. As do GP4/GP5 descem duas fileiras no canal entre o RP e o soquete do TMC. - UART no pino 4 do StepStick. Nos módulos TMC2209 comuns (e no usado nos testes), o PDN_UART fica na posição do MS3 (pino 4), não no pino 5. O JU liga o GP2 ao pino 4, com o R7 (10k) como pull-up. O pino 5 fica livre. Módulos com a UART no pino 5 (Watterott SilentStepStick) deixam de servir. - Sem o jumper ZM. Com a UART, o Klipper tira o micropasso do cfg ( mstep_reg_select ) e MS1/MS2 só dão o endereço; com um driver por RP, o endereço é fixo. R4 e R5 ficam: MS1 = MS2 = 1, endereço 3 (o mesmo do cfg) e 1/16 em standalone. O jumper MS3 antigo, que aterraria a UART, sai junto. ⚠️ Placas até a v17: a UART vai ao pino 5. Com esse módulo, ligue um fio do JU.2 ao pino 4 e deixe o MS3 do ZM aberto. - Nenhuma curva de trilha de 90°. Cada canto de 90° virou dois de 135°, com um trecho a 45° de 1 mm de perna. Junções em T continuam. A regra entrou na validação: a v17 tinha 18 cantos, a v18 tem 0. - Segundo NTC (J8, GP26). Com dois motores na placa, cada um

ScaraNode · Rev. v18 · 27/09/2026 | Projetista: Daniel M. Torres | 42 / 44

tem o seu termômetro. O pull-up (R15, 100k) fica deitado na vertical, ao lado do soquete do RP, do 3V3 ao GP26. O C1 e o C4 saíram dessa coluna e foram para o vão entre o R3 e o R2, e o C7 (100 nF) fica abaixo do R8. Os quatro conectores da esquerda (NTC1, FIM1, NTC2, FIM2) ficam a 6,05 mm uns dos outros, e a trilha de 5 V desceu 1,1 mm para o J2 caber. Com o GP26 ocupado, sobram GP3, GP14 e GP28: o ADXL345 (só SPI no Klipper) não cabe mais; use um acelerômetro I2C. - Fusível por placa, na caixa central. Um TMC2209 pegou fogo a 1,7 A (acima dos 1,0–1,2 A que o StepStick aguenta), e o fusível único da máquina, dimensionado para tudo, não abriu. Agora cada placa tem o seu fusível de 2 A, e cada DM556 o seu de 5 A, numa caixa de fusíveis de lâmina automotiva (32 V DC, fácil de achar). Ficou fora da placa: os DM556 também precisam de fusível e não passam por ela, e um porta-fusível de placa barato e fácil de achar não coube na faixa de 24 V com as duas brocas. Detalhes e contas no capítulo 6. - Segunda ventoinha (J9), sempre ligada, entre o D2 e o D1: J7 no TMC2209, J9 no DM556 ou na caixa. - Conectores plugáveis 2EDG (5,08 mm) no lugar dos bornes de parafuso: J5 (24 V) macho 90° 2EDGRC com o plugue entrando pela borda de cima; J6 (motor) macho vertical 2EDGVC, plugue por cima e fio para a direita. Plugue 2EDGK nos dois. O J6 desceu 1,6 mm (o macho é mais comprido e encostava no parafuso do H2). - Furos M3 esquadrados: o H2 foi para o canto de cima (retângulo de 69 × 57 mm com os outros três). O J5 foi 5,6 mm para a esquerda e o D1 4,5 mm; a 24 V passa a descer pelo R9 até o C10 e do C10 ao VM do TMC. - Validado: 128 pinos, 0 violações de cobre, 0 ligações faltando, ERC e paridade 0.

## v17 — esquemático e resistores iguais

Esquemático em hardware/ScaraNode.kicad_sch e em PDF: uma folha, blocos por função, rótulos na ponta dos pinos. ERC sem erro nem aviso; paridade placa × esquemático sem divergência. Símbolos próprios em hardware/ScaraNode.kicad_sym , footprints próprios em hardware/ScaraNode.pretty . Pinos livres ganham na placa a rede unconnected-(…) que o esquemático gera; o cobre não muda. R13 e R14 passam a 1/4 W, furos a 10,16 mm (antes 1/8 W a 7,62): os 13 resistores são iguais. Continuam embaixo do RP2040-Zero.
Coluna da esquerda (XH, R2/R3/R8, C1/C4/C5, barra fêmea do RP) com folgas iguais entre corpos: ~0,9 mm do XH à perna do R e da perna do R ao capacitor (medidas com perna de 0,8 mm, acima da real), ~1,0 mm do capacitor à barra fêmea. O capacitor para no limite da isolação de 0,6 mm com as ilhas livres do RP.
As exceções de courtyard deixam de ser uma lista fixa: onde os courtyards se sobrepõem ou os corpos ficam a menos de 2 mm, a folga real entre os corpos (desenho de fabricação, pernas pelo furo) tem que ser ≥ 0,10 mm. Menor folga: 0,30 mm (J7 × cabeça do M3 do H1). O DRC do KiCad continua marcando 13 sobreposições de courtyard como erro; são essas, conferidas pela folga real.
Sem jumper de fio: o U2 (74ACT245), o C2 e a trilha de 5 V que chega a eles descem 1 mm; o J4 fica onde estava. O plano de GND passa a chegar à coluna da esquerda (NTC e fins de curso) entre o último pino do RP2040-Zero e a trilha de 5 V, e o JP1 (fio de GND por cima da trilha de 5 V) sai da placa, da lista de materiais e da montagem. O J4 fica a ~0,5 mm do soquete do U2; o U2 se afasta do RP (~1,7 mm).
R13 e R14 inclinados a 50°, paralelos: a ilha do fim de curso fica na altura do GP27/GP15 (trilhas retas) e a ilha de 3V3 dos dois cai na mesma trilha de 3V3, que agora desce a ~9,4 mm da fileira esquerda do RP (antes descia a 3,2 mm). Com isso o GND do RP2040-Zero liga direto ao plano de GND de cima por um canal de ~6 mm. O R6 passa um pouco para a direita (1,3 mm) e o EN chega a ele em L, sem ilha de cobre solta a mais. Folgas: R13 × R14, R13 × R6 e R14 × R6 ~0,8 mm; R13/R14 a ~1,2 mm da barra fêmea; R6 a ~0,9 mm da barra da direita.
Renders com as faixas de cor de cada resistor.
Validado: 126 pinos, ERC 0, paridade 0, 0 violações de cobre, 0 ligações faltando. Furação: 118 × 1,0 · 8 × 1,6 · 4 × 3,2.

ScaraNode · Rev. v18 · 27/09/2026 | Projetista: Daniel M. Torres | 43 / 44

## v16 — dimensões redondas, soquete DIP e DXF

Contorno passa de 75,8 × 64 para 76 × 64 mm (borda direita +0,2 mm).
Furos M3 a 3,5 mm das bordas: H1/H3/H4 num retângulo de 69 × 57 mm; H2 na coluna do H4, 18 mm abaixo da borda de cima. Antes: H1 e H3 desalinhados 0,2 mm, cotas quebradas.
U2 com footprint de soquete DIP-20 (mesmos furos, corpo maior). Exceção medida: o corpo do soquete termina a ~1 mm da perna do R7.
production/ScaraNode-mecanico.dxf : contorno, furos e cotas.
Coluna da esquerda reorganizada: NTC (J3) sozinho em cima e os dois fins de curso (J1, J2) juntos mais abaixo, com um vão de ~9 mm entre os grupos. O J2 fica no limite da trilha de 5 V (y = 41,2). LED de 5 mm (mesmo passo de 2,54 mm e furo de 1,0 mm do de 3 mm); o R12 subiu 1 mm para ele caber. Folgas medidas: LED a ~0,7 mm do J3; J1 a ~1,6 mm da perna do R8.
Validado: 128 pinos, 0 violações de cobre, 0 ligações faltando.

## v15 — conectores JST XH

J1, J2, J3, J4 e J7 trocam o footprint Molex KK (2,54 mm) pelo JST XH (B2B/B4B-XH-A, 2,5 mm), que é o conector usado de fato. As ilhas continuam ovais de 1,8 × 2,4 mm com furo de 1,0 mm.
J4: as trilhas do 74ACT245 (passo 2,54) fazem um desvio curto até os pinos do XH (passo 2,5).
O corpo do XH é mais largo que o do KK. Exceções de courtyard aceitas, com as medidas do F.Fab: J1/J2/J3 × R2/R3/R8 (plástico a ~0,2 mm da perna do resistor, sem cobre no meio) e J7 × H1/D2 (~1 mm da cabeça do M3, ~1,5 mm da perna do D2). Afastar a coluna para a esquerda violaria a isolação da trilha de 5 V.
U2 soldado direto (sem soquete DIP). Borne J5 verde (24 V), J6 azul (motor).
Validado: 128 pinos, 0 violações de cobre, 0 ligações faltando. Furação igual: 120 × 1,0 · 8 × 1,6 · 4 × 3,2.

## v14 — ENA do DM556 e pull-ups dos fins de curso

ENA: GP8 → B3 do 74ACT245 (pino 16, antes em GND) → A3 (pino 4) → J4.4. O J4 passa a KF2510 de 4 vias: 5V, PUL−, DIR−, ENA−, com o ENA+ do DM556 no 5 V como PUL+/DIR+. GP8 alto = motor habilitado ( enable_pin: gpio8 , sem ! ). Com o RP em reset ou em boot, o GP8 fica baixo e o DM556 fica desabilitado até o Klipper assumir.
Pull-ups de 10k R13 (GP27/FIM1) e R14 (GP15/FIM2) do lado do RP, embaixo do módulo. São de 1/8 W (DIN0204, furos a 7,62 mm), porque o de 1/4 W encostava no soquete. O R14 fica inclinado 60°. Exceção de DRC aceita: o canto do courtyard do R14 invade ~0,2 mm o do soquete do RP. A ilha fica a 0,68 mm do plástico.
Validado: 128 pinos, 0 violações de cobre, 0 ligações faltando.

## v13 — só duas brocas

Furos ≤ 1,2 mm viram 1,0 mm; entre 1,2 e 3,0 mm viram 1,6 mm; 3,2 mm (M3) fica. As ilhas cresceram onde foi preciso para manter o anel ≥ 0,4 mm.
Pinos 1 e 19 do U2 com ligação sólida ao plano (não cabia o alívio térmico).

## v12 — C10 de 470 µF

C10 = 470 µF 35 V (Ø10 mm, passo 5 mm), para absorver a energia de frenagem com o D1 em série. Com 470 µF, o VM sobe a ~27,4 V na frenagem estimada; com 100 µF chegava a ~30 V.
A faixa de 24 V inteira subiu 4 mm para o capacitor caber; a placa passou a 75,8 × 64 mm.

ScaraNode · Rev. v18 · 27/09/2026 | Projetista: Daniel M. Torres | 44 / 44

## v11 — jumper de UART

JU (1x2) entre o RP e o TMC: JU.2 ← GP5, JU.1 → pino 5 do StepStick (PDN_UART). Aberto = standalone. Sem resistor e sem pull-up: UART de 1 fio half-duplex.
Os pinos 5–6 do soquete não ficam mais livres para o curto RST/SLP de A4988/DRV8825.

## v10 — LED na borda e retorno de GND

D3 na borda esquerda, abaixo do R12.
Trilha de GND de 2,5 mm do borne J5 até o C10 e dali ao pino 15 do TMC: caminho sólido para os pulsos do chopper, sem depender dos raios do alívio térmico.

## v9 — pronta para fresar

Conectores KK com ilha oval de 1,8 × 2,4 mm e furo de 1,0 mm (anel de 0,40 mm; a biblioteca deixava 0,28 mm).
Menor vão entre redes: 0,601 mm. Menor anel: 0,40 mm.
Primeiros Gerbers e a regra de espelhamento para fresar com o cobre para cima.

## Decisões de projeto que valem para todas as revisões

Fresa desconhecida → regras seguras: isolação de 0,6 mm, sinal de 1,2 mm, ilhas generosas. Ilhas de cobre soltas são mantidas: sobra menos cobre para a fresa tirar.
Sem entrada de 5 V: o USB é obrigatório para o Klipper e já alimenta a lógica.
Pino 6 (CLK) do StepStick livre: aterrar sem medir o módulo pode danificar variantes que usam esse pino para outra coisa.
Sem homing sensorless: o módulo usado não expõe o DIAG; o homing é por chave (J1/J2).
Fusível da 24 V: fora da placa, na caixa central, mas um por placa (2 A) e um por DM556 (5 A) desde a v18.
LED: R12 = 10k (~2,2 mA). Para mais brilho, R12 = 4k7 (~4,6 mA).

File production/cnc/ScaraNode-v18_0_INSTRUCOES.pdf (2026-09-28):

## ScaraNode v18 — instruções para a fresa CNC

Projetista: Daniel M. Torres · Revisão v18 · 27/09/2026 · github.com/DanielMTorres7/scaranode

### Resumo

Placa de face única: cobre só de um lado. 76 × 64 mm, FR-4 (ou fenolite) de 1,6 mm.
Quantidade: ______ placas.
Cada arquivo abaixo é uma ferramenta; o nome do arquivo já diz a operação e a ferramenta. Faça na ordem.
Todos os arquivos têm a mesma origem (coordenadas absolutas, em mm). Não mova um arquivo sem mover os outros.

### Operações, na ordem

# | Arquivo | Operação | Ferramenta | Observação

1 ScaraNode-v18_1 | _ISOLACAO_fresa -ate-0.6mm.gbl | Isolação das trilhas (cobre) | fresa com largura de corte de até 0,6 mm (fresa V 20–30° ou fresa de topo de 0,5 mm) | Menor vão entre cobres: 0,6 mm, em todo lugar. Uma passada já isola. As ilhas de cobre soltas podem ficar: não precisa limpar o cobre em volta.
2 ScaraNode-v18_2 | _FURO_broca-1.0 mm_120-furos.dr l | Furação: 120 furos | broca de 1,0 mm | pernas finas (resistores, capacitores, CI, conectores pequenos, barras de pinos)
3 ScaraNode-v18_3 | _FURO_broca-1.6 mm_8-furos.drl | Furação: 8 furos | broca de 1,6 mm | pernas grossas: diodo D1 e conectores de 24 V (J5) e do motor (J6)
4 ScaraNode-v18_4 | _FURO_broca-3.2 mm_4-furos.drl | Furação: 4 furos | broca de 3,2 mm | furos de fixação M3, sem cobre, nos 4 cantos
5 ScaraNode-v18_5 | _CONTORNO_fresa -topo-1.0-a-2.0 mm.gm1 | Corte do contorno (76 × 64 mm) | fresa de topo de 1,0 a 2,0 mm | Cortar por fora da linha, na espessura toda, com 2 a 4 pontes para a placa não soltar. Por último.

⚠ Espelhamento — o erro que perde a placa. Os arquivos estão desenhados vistos pelo lado dos componentes (o lado sem cobre). Se a placa for fresada com o cobre virado para cima, espelhe todos os arquivos (cobre, furos e contorno) no mesmo eixo (ex.: FlatCAM, Mirror no eixo Y). Confira com a imagem da página 2, que mostra a placa como ela fica olhando o cobre: os conectores grandes de 24 V e do motor ficam à esquerda, e a fileira de conectores pequenos (NTC e fins de curso) à direita.

### Cuidados

Anel de cobre em volta dos furos: mínimo de 0,4 mm. Use broca afiada e fure antes do contorno, com a placa bem presa, para não arrancar as ilhas.
Os furos de 3,2 mm (M3) não têm cobre em volta.
Os furos de 1,0 mm recebem barras de pinos de 0,64 mm: posição precisa importa mais que o diâmetro. Dúvidas: falar com Daniel M. Torres.

### Conferência: placa vista pelo lado do cobre (já espelhada)

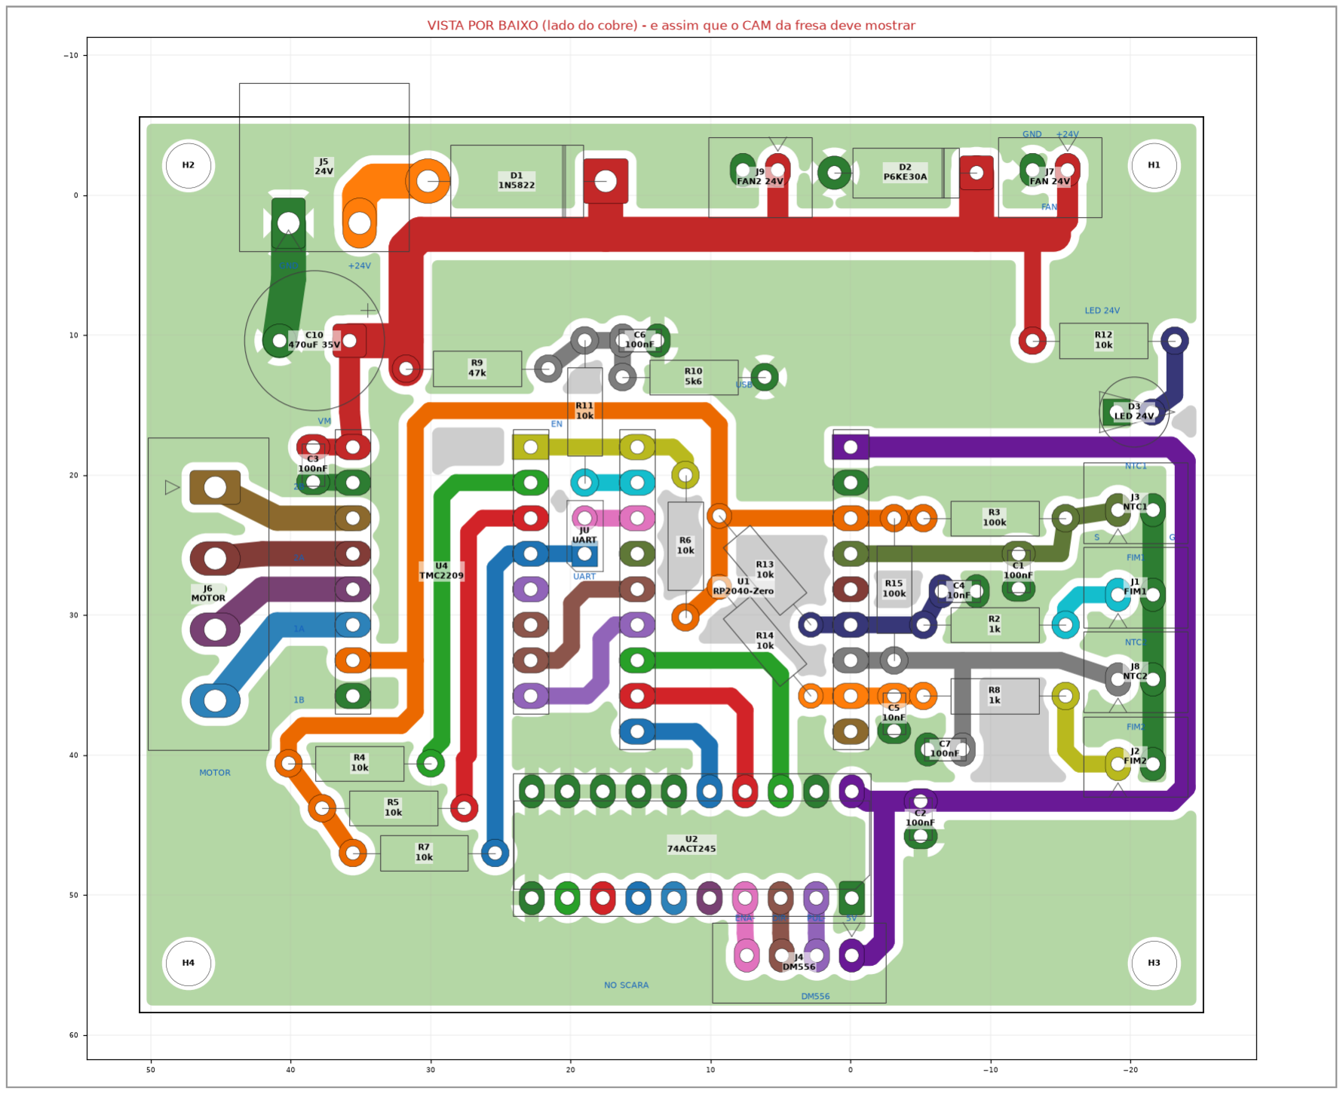
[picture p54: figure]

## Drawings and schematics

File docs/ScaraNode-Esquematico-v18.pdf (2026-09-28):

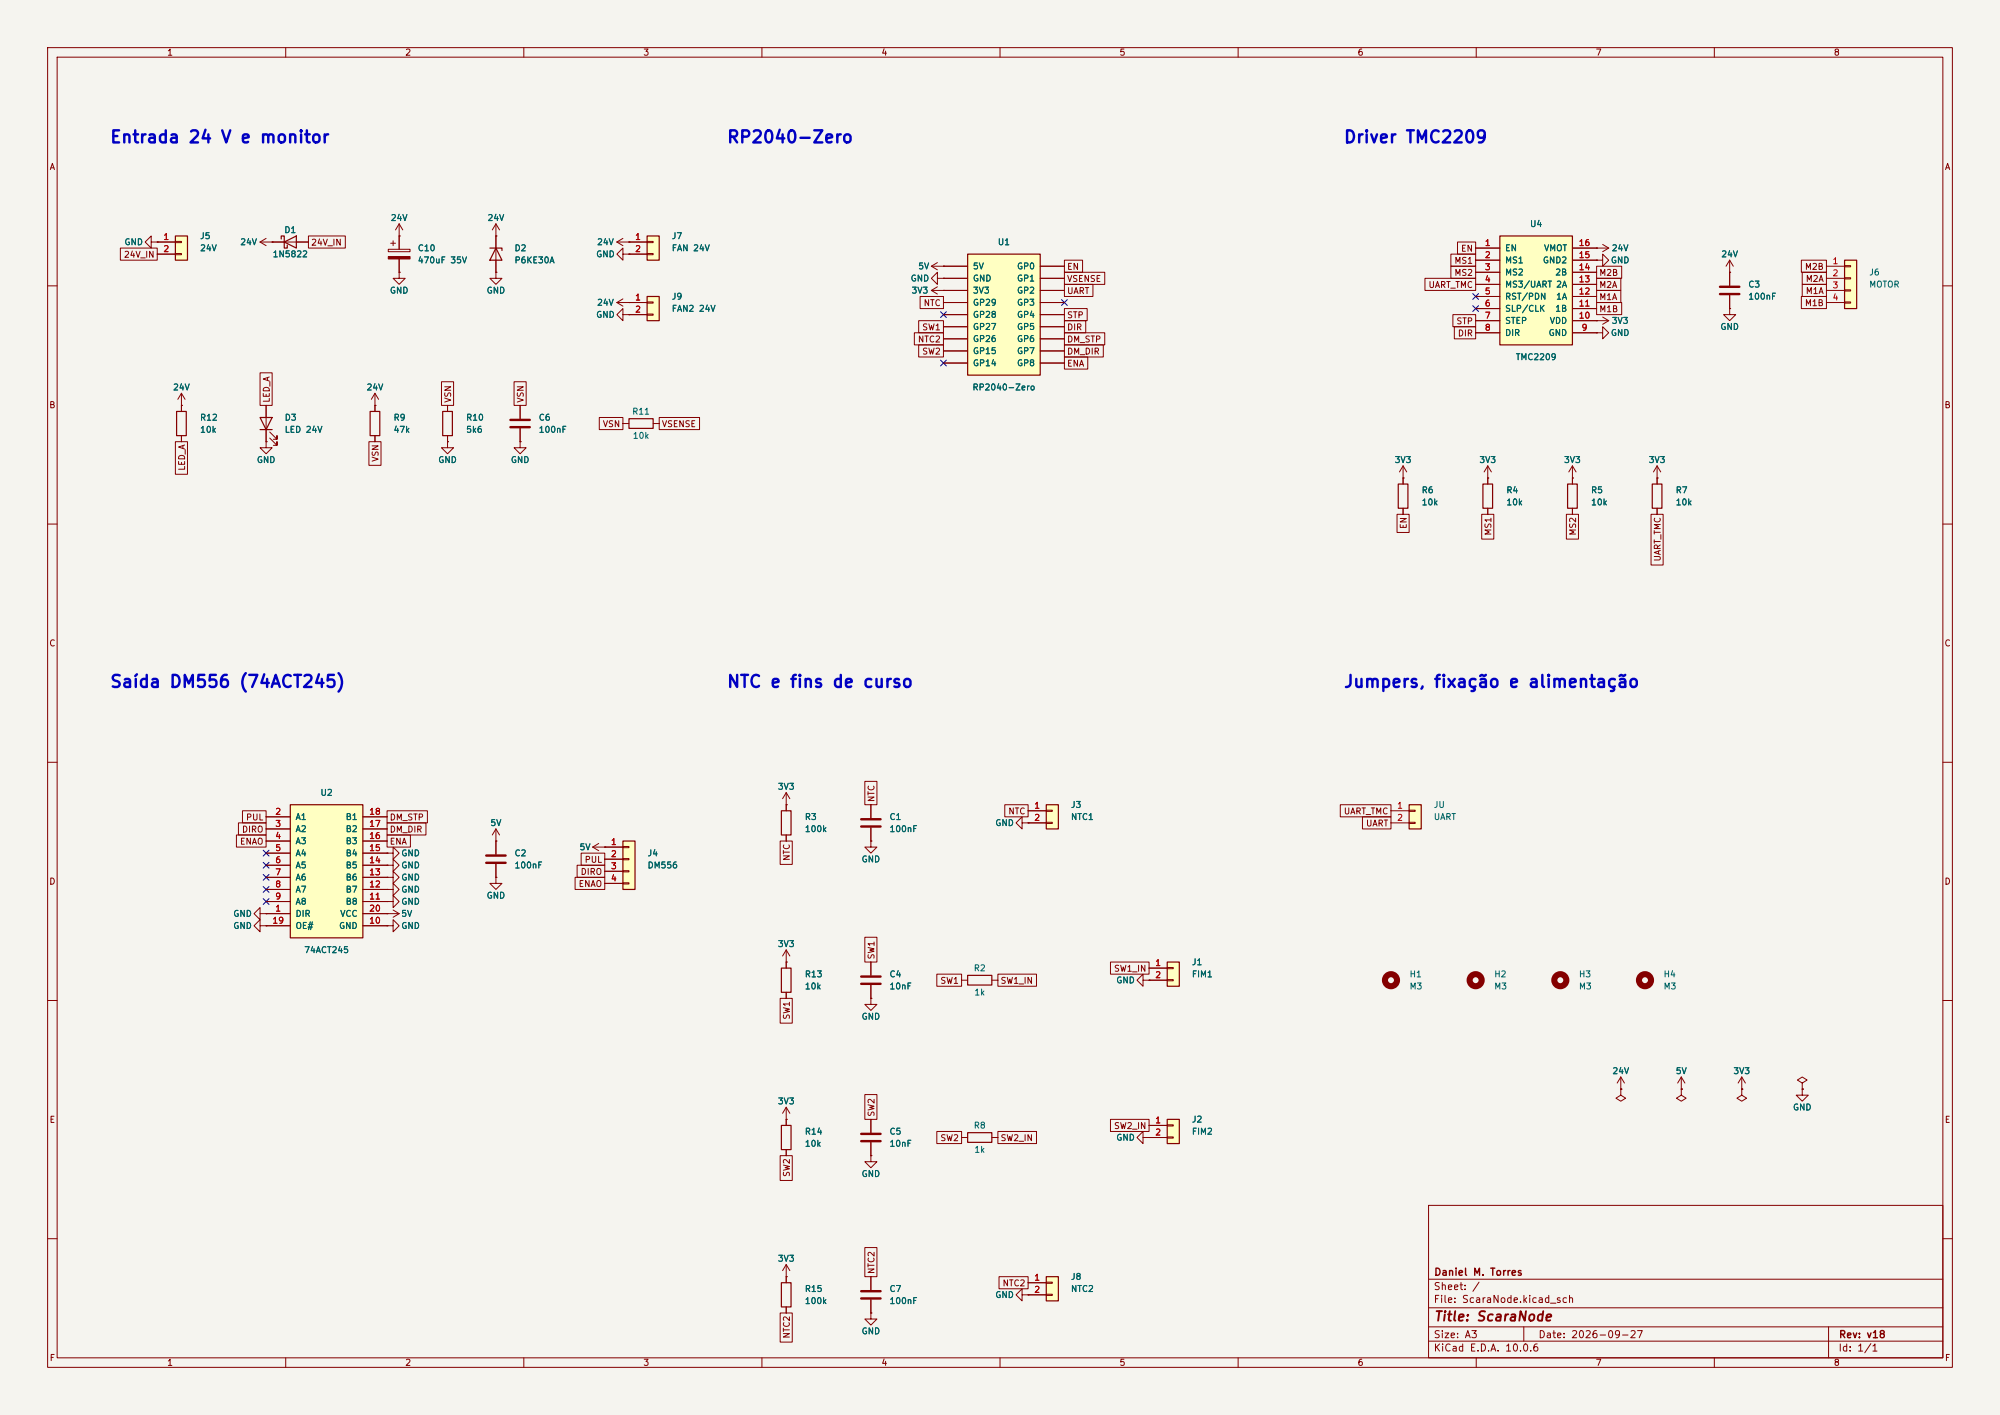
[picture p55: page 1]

NTC e fins de curso

Size: A3 | Rev: v18 | F Date: 2026-09-27
KiCad E.D.A. 10.0.6 | Id: 1/1

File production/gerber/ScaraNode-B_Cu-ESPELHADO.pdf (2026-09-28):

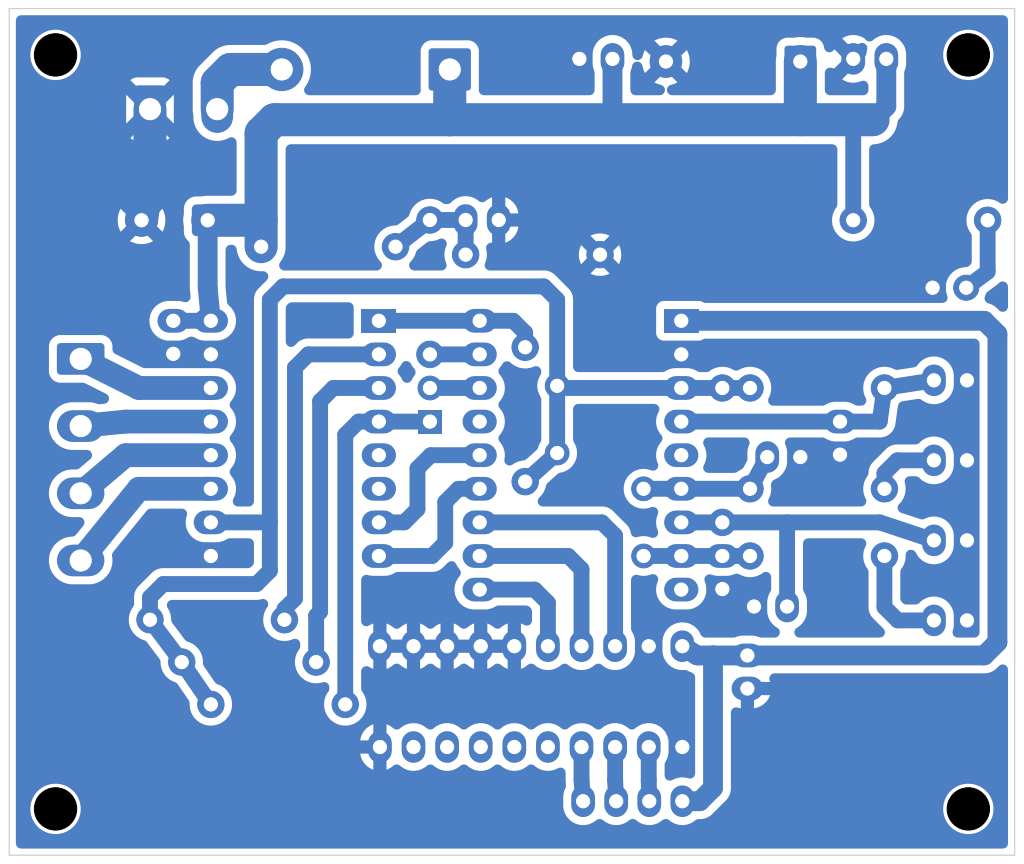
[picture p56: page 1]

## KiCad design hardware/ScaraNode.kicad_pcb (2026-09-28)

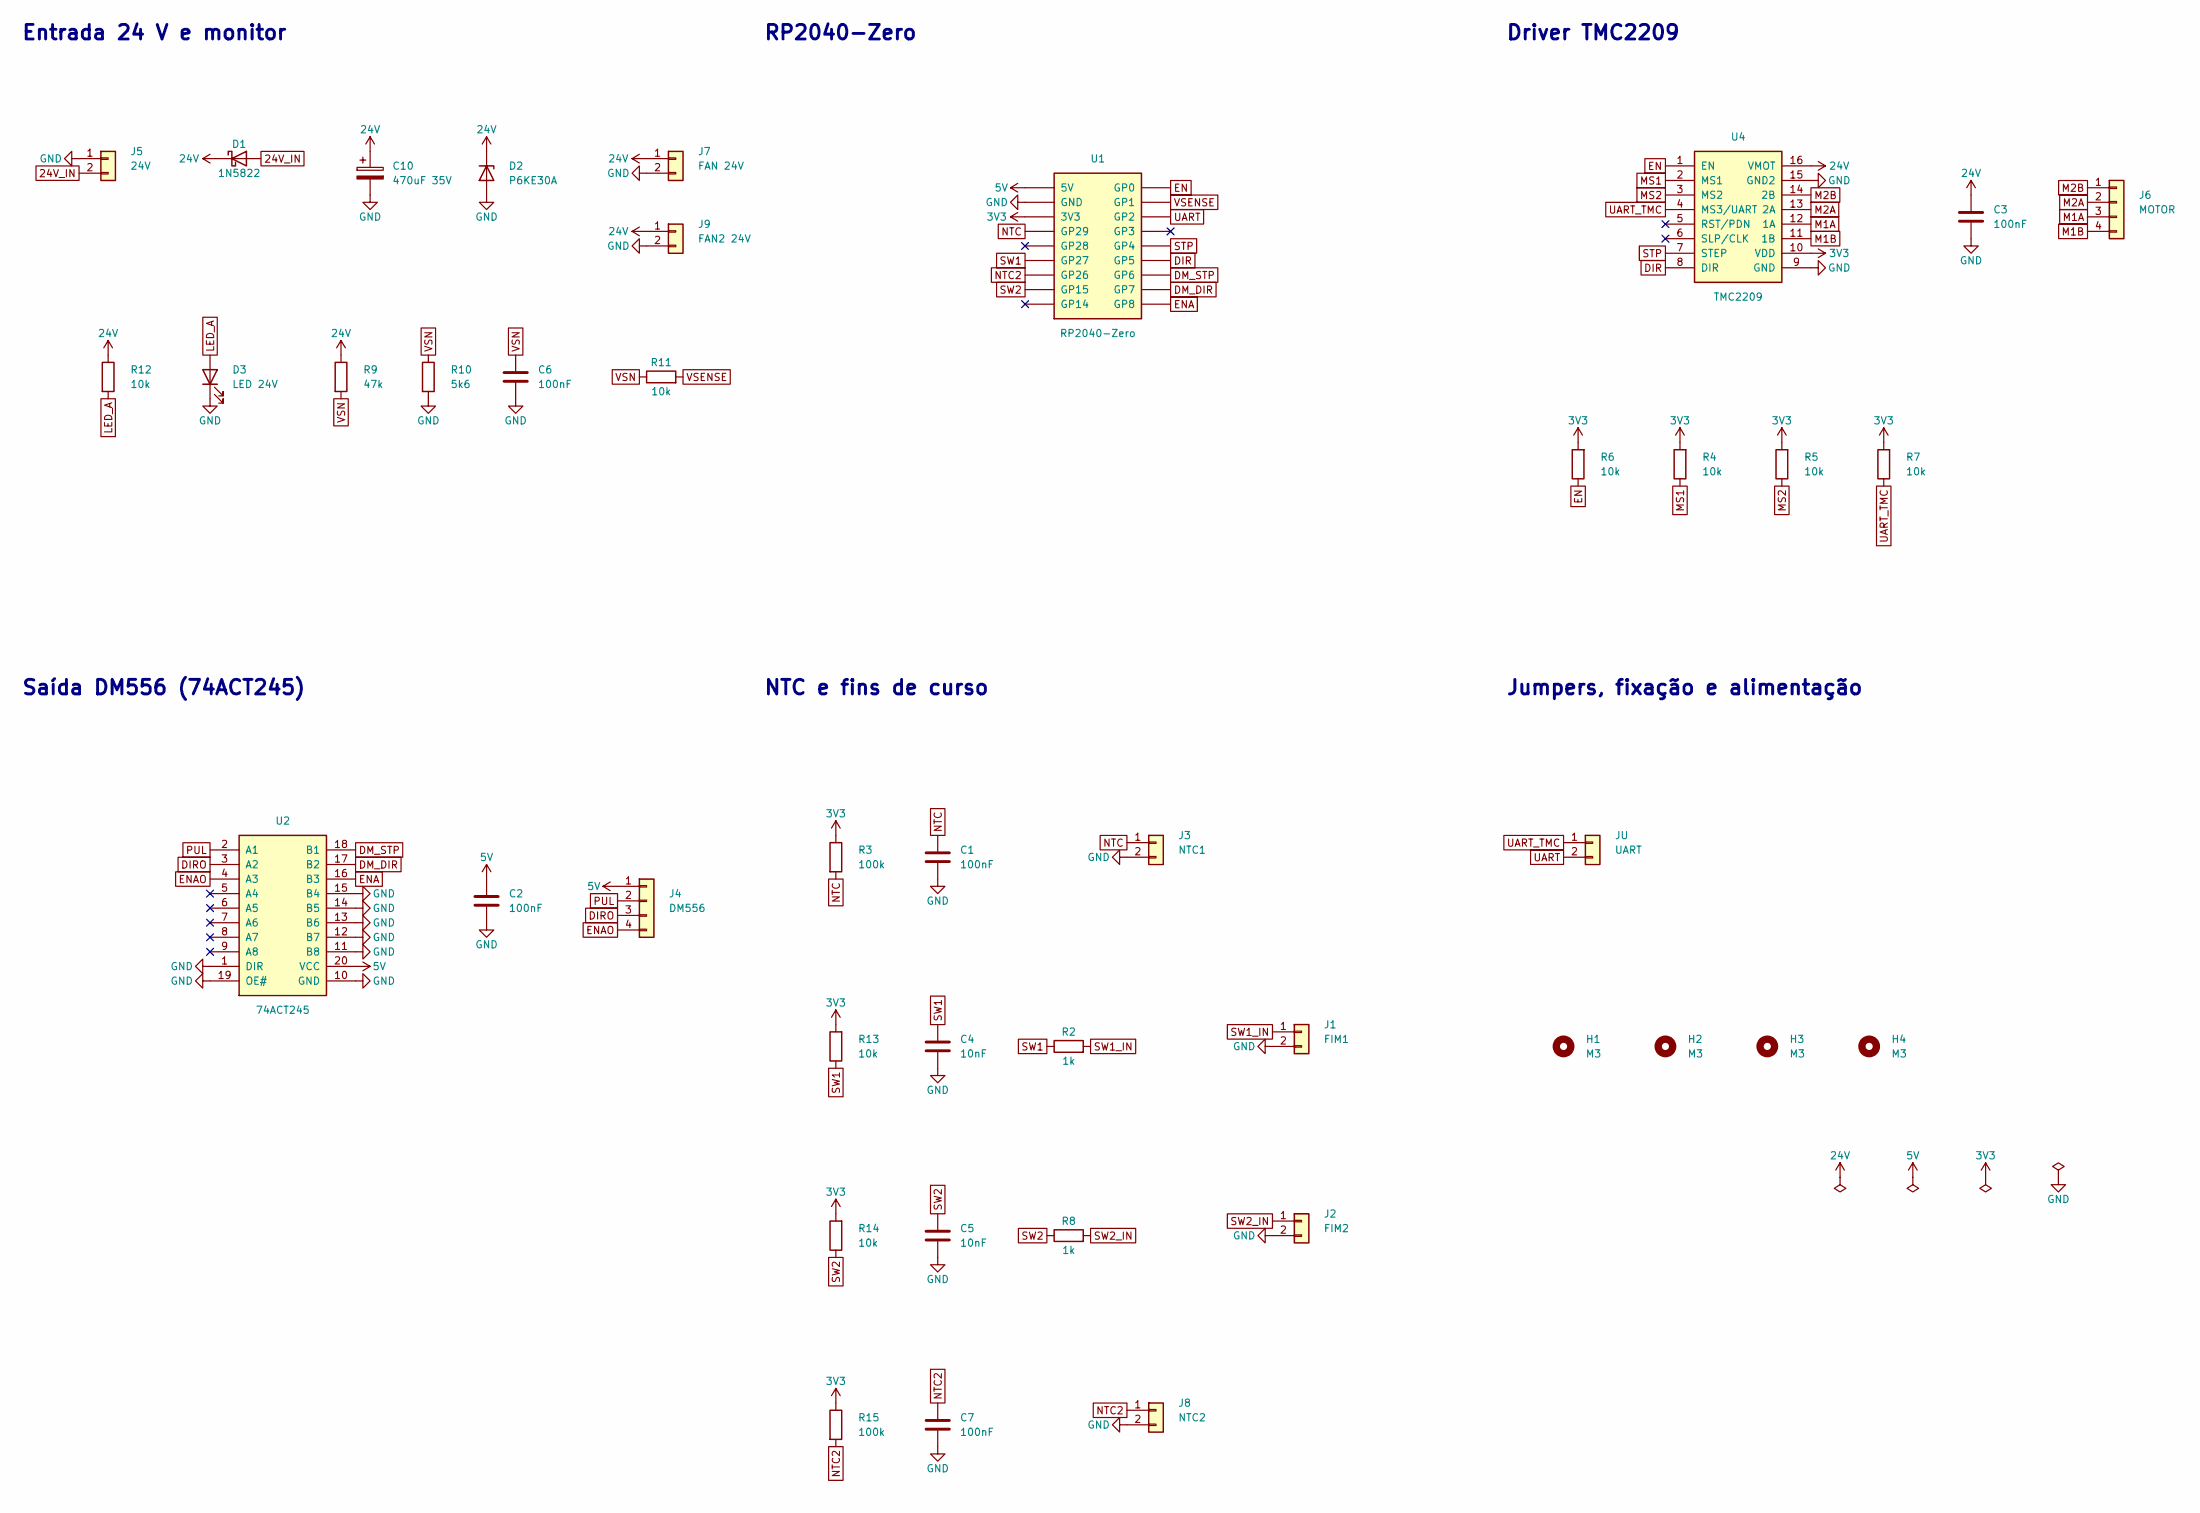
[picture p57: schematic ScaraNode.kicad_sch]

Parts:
C1, C2, C3, C6, C7: 100nF; C_Disc_D3.0mm_W1.6mm_P2.50mm
C4, C5: 10nF; C_Disc_D3.0mm_W1.6mm_P2.50mm
C10: 470uF 35V; CP_Radial_D10.0mm_P5.00mm
D1: 1N5822; D_DO-201AD_P12.70mm_Horizontal
D2: P6KE30A; D_DO-15_P10.16mm_Horizontal
D3: LED 24V; LED_D5.0mm
H1, H2, H3, H4: M3; MountingHole_3.2mm_M3
J1: FIM1; JST_XH_B2B-XH-A_1x02_P2.50mm_Vertical
J2: FIM2; JST_XH_B2B-XH-A_1x02_P2.50mm_Vertical
J3: NTC1; JST_XH_B2B-XH-A_1x02_P2.50mm_Vertical
J4: DM556; JST_XH_B4B-XH-A_1x04_P2.50mm_Vertical
J5: 24V; PhoenixContact_MSTBA_2,5_2-G-5,08_1x02_P5.08mm_Horizontal
J6: MOTOR; PhoenixContact_MSTBVA_2,5_4-G-5,08_1x04_P5.08mm_Vertical
J7: FAN 24V; JST_XH_B2B-XH-A_1x02_P2.50mm_Vertical
J8: NTC2; JST_XH_B2B-XH-A_1x02_P2.50mm_Vertical
J9: FAN2 24V; JST_XH_B2B-XH-A_1x02_P2.50mm_Vertical
JU: UART; PinHeader_1x02_P2.54mm_Vertical
R2, R8: 1k; R_Axial_DIN0207_L6.3mm_D2.5mm_P10.16mm_Horizontal
R3, R15: 100k; R_Axial_DIN0207_L6.3mm_D2.5mm_P10.16mm_Horizontal
R4, R5, R6, R7, R11, R12, R13, R14: 10k; R_Axial_DIN0207_L6.3mm_D2.5mm_P10.16mm_Horizontal
R9: 47k; R_Axial_DIN0207_L6.3mm_D2.5mm_P10.16mm_Horizontal
R10: 5k6; R_Axial_DIN0207_L6.3mm_D2.5mm_P10.16mm_Horizontal
U1: RP2040-Zero; RP2040-Zero_Socket
U2: 74ACT245; DIP-20_W7.62mm_Socket_LongPads
U4: TMC2209; StepStick_Socket

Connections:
3V3: R3.1, R4.2, R5.2, R6.2, R7.2, R13.2, R14.2, R15.1, U1.3V3, U4.10 (VDD)
5V: C2.1, J4.1, U1.5V, U2.20 (VCC)
24V: C3.1, C10.1, D1.1 (K), D2.1 (K), J7.1, J9.1, R9.1, R12.1, U4.16 (VMOT)
24V_IN: D1.2 (A), J5.2
DIR: U1.GP5, U4.8 (DIR)
DIRO: J4.3, U2.3 (A2)
DM_DIR: U1.GP7, U2.17 (B2)
DM_STP: U1.GP6, U2.18 (B1)
EN: R6.1, U1.GP0, U4.1 (EN)
ENA: U1.GP8, U2.16 (B3)
ENAO: J4.4, U2.4 (A3)
GND: C1.2, C2.2, C3.2, C4.2, C5.2, C6.2, C7.2, C10.2, D2.2 (A), D3.1 (K), J1.2, J2.2, J3.2, J5.1, J7.2, J8.2, J9.2, R10.2, U1.GND, U2.1 (DIR), U2.10 (GND), U2.11 (B8), U2.12 (B7), U2.13 (B6), U2.14 (B5), U2.15 (B4), U2.19 (OE#), U4.9 (GND), U4.15 (GND2)
LED_A: D3.2 (A), R12.2
M1A: J6.3, U4.12 (1A)
M1B: J6.4, U4.11 (1B)
M2A: J6.2, U4.13 (2A)
M2B: J6.1, U4.14 (2B)
MS1: R4.1, U4.2 (MS1)
MS2: R5.1, U4.3 (MS2)
NTC: C1.1, J3.1, R3.2, U1.GP29
NTC2: C7.1, J8.1, R15.2, U1.GP26
PUL: J4.2, U2.2 (A1)
STP: U1.GP4, U4.7 (STEP)
SW1: C4.1, R2.1, R13.1, U1.GP27
SW1_IN: J1.1, R2.2
SW2: C5.1, R8.1, R14.1, U1.GP15
SW2_IN: J2.1, R8.2
UART: JU.2, U1.GP2
UART_TMC: JU.1, R7.1, U4.4 (MS3/UART)
VSENSE: R11.2, U1.GP1
VSN: C6.1, R9.2, R10.1, R11.1

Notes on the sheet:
Entrada 24 V e monitor
RP2040-Zero
Driver TMC2209
Saída DM556 (74ACT245)
NTC e fins de curso
Jumpers, fixação e alimentação

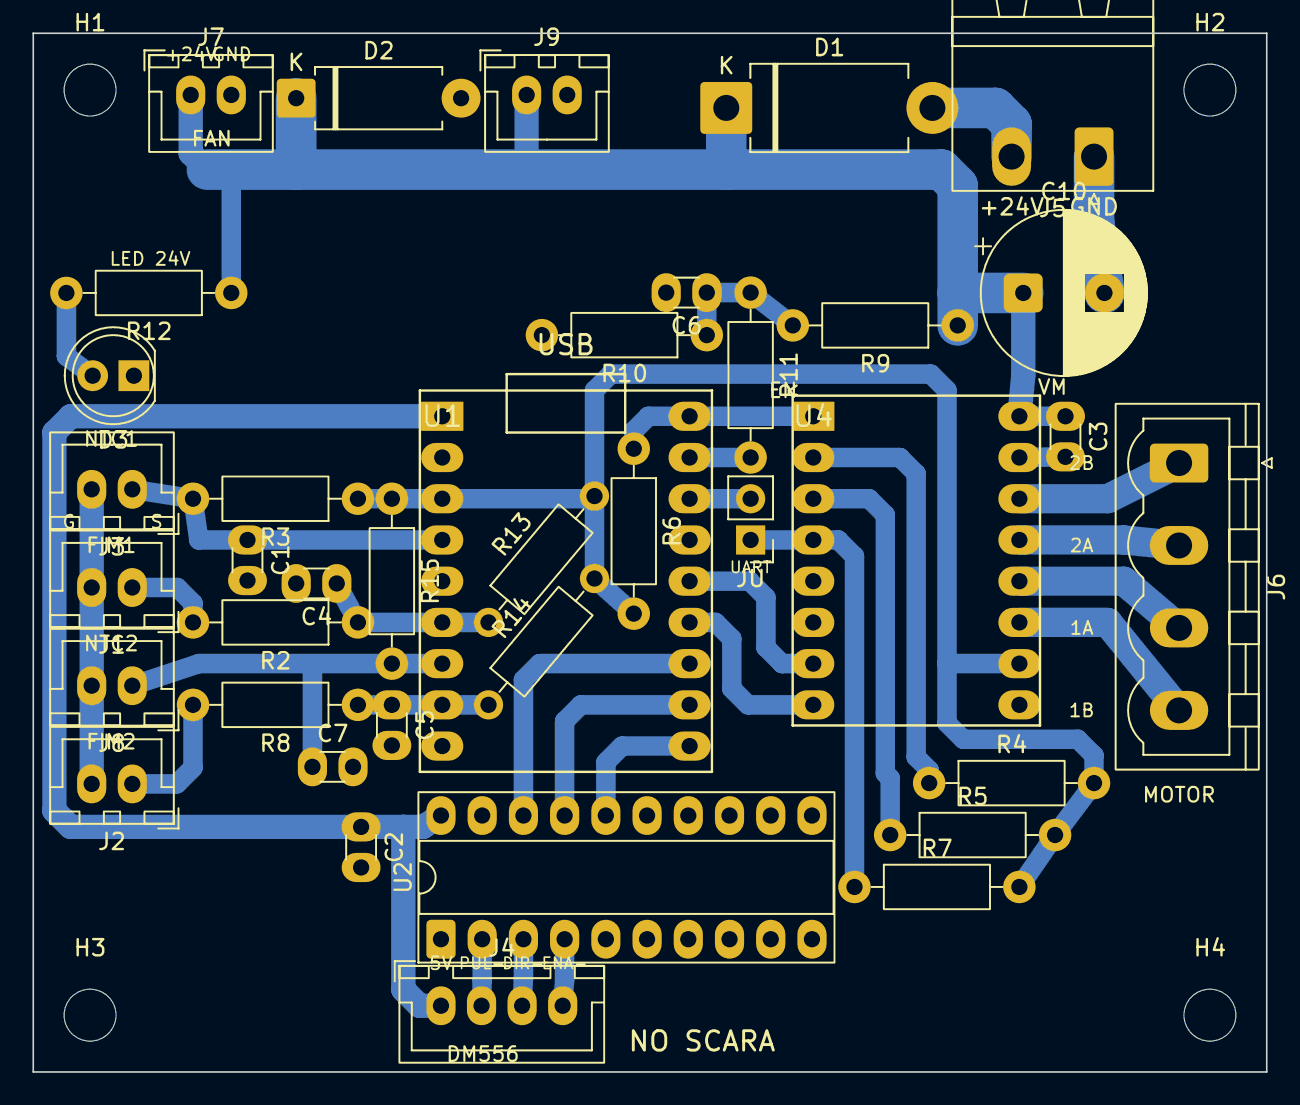
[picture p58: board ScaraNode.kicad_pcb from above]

Board: 2 copper layers, 76.0 x 64.0 mm, 42 parts (0 on the bottom side), 31 nets.

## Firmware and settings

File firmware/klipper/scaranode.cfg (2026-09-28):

# =====================================================================================
#  ScaraNode rev. v18 — configuração Klipper de REFERÊNCIA
#  Projetista: Daniel M. Torres · 27/09/2026
#
#  Montada a partir da placa (hardware/ScaraNode.kicad_pcb, pinagem conferida pino a pino),
#  não copiada do printer.cfg da máquina. A cinemática SCARA (scara.py / kin_scara.c) e os
#  valores mecânicos (rotation_distance, limites, velocidades) são da máquina, não da placa:
#  estão marcados com  # AJUSTAR.
#
#  Um RP2040-Zero por nó. Cada nó vira um [mcu <nome>] e os pinos levam o prefixo "<nome>:".
#  Aqui: j2 = nó com TMC2209 (NEMA 17) e j1 = nó com DM556 externo (NEMA 23).
#  Nós iguais (j3, z) repetem o bloco trocando o nome e o serial.
#  Desde a v18 o TMC2209 e o DM556 têm STEP/DIR/enable próprios: um nó pode mover dois motores
#  ao mesmo tempo, um em cada driver. Nesse caso o FIM1 (gpio27) fica com o eixo do TMC e o
#  FIM2 (gpio15) com o do DM556 (cada chave no mesmo MCU do seu motor).
#
#  Pinagem da placa (RP2040-Zero):
#    GP0  EN do TMC2209 (ativo baixo, pull-up 10k R6)      GP6  STEP do DM556 (via 74ACT245)
#    GP1  monitor de 24 V (divisor 47k/5k6, ~2,5 V)        GP7  DIR  do DM556 (via 74ACT245)
#    GP2  PDN_UART do TMC2209 (pino 4) via jumper JU       GP8  ENA do DM556 (alto = habilitado)
#    GP4  STEP do TMC2209                                  GP5  DIR  do TMC2209
#    GP15 fim de curso 2 (J2, pull-up 10k R14)             GP27 fim de curso 1 (J1, pull-up 10k R13)
#    GP29 NTC1 no J3 (ADC3, pull-up 100k R3)               GP26 NTC2 no J8 (ADC0, pull-up 100k R15)
#
#  ⚠ PARA NÃO QUEIMAR O DRIVER (um TMC2209 pegou fogo a 1,7 A em 27/09/2026):
#    1. run_current do TMC2209 no MÁXIMO 1,0–1,2 A. O StepStick não dissipa mais que isso.
#       Motor que precisa de mais corrente vai no DM556.
#    2. Use a UART (JU fechado + seção [tmc2209]). Só com ela o Klipper lê os avisos de
#       temperatura do TMC e para a máquina antes de queimar; em standalone ninguém vigia o driver.
#    3. NUNCA ligue/desligue o cabo do motor com a 24 V ligada: o pico mata o driver na hora.
#    4. Ponteira (terminal tubular) nos fios do borne do motor e da 24 V, bem apertados.
#    5. Um fusível de 2 A SÓ para esta placa na caixa de fusíveis (docs/06-circuitos.md).
# =====================================================================================

# -------------------------------------------------------------------------------------
#  Nó J2 — NEMA 17 + TMC2209 no soquete U4
# -------------------------------------------------------------------------------------
[mcu j2]
serial: /dev/serial/by-id/usb-Klipper_rp2040_XXXXXXXXXXXXXXXX-if00   # AJUSTAR: ls /dev/serial/by-id/

[stepper_j2]                          # o nome segue a sua cinemática SCARA  # AJUSTAR
step_pin: j2:gpio4
dir_pin: j2:gpio5                     # motor girando ao contrário: !j2:gpio5
enable_pin: !j2:gpio0                 # EN do TMC2209 é ativo em nível baixo
microsteps: 16                        # com UART vem daqui; em standalone o TMC fica fixo em 1/16
rotation_distance: 360                # AJUSTAR: graus por volta da junta
gear_ratio: 6:1, 4:1                  # AJUSTAR: planetária 6:1 + correia 4:1
endstop_pin: !j2:gpio27               # chave NA para GND. Chave NF: j2:gpio27 (sem !)
# position_endstop / position_min / position_max / homing_speed   # AJUSTAR

# Recomendado: UART (JU FECHADO). Com o JU aberto, comente esta seção: o driver fica em
# standalone (corrente pelo trimpot, micropasso fixo em 1/16) e o Klipper não vigia a temperatura dele.
[tmc2209 stepper_j2]
uart_pin: j2:gpio2                    # PDN_UART no pino 4 do soquete (v18; até a v17 era gpio5 no pino 5)
uart_address: 3                       # MS1 e MS2 fixos em 1 pelo R4/R5 (v18, sem jumper ZM)
run_current: 1.0                      # ⚠ MÁXIMO 1,2 (A RMS) no StepStick, com ventoinha no J7
sense_resistor: 0.110                 # RSENSE R110 do módulo usado
stealthchop_threshold: 0              # 0 = spreadCycle sempre

[temperature_sensor motor_j2]
sensor_type: Generic 3950             # NTC 100k B3950 no J3
sensor_pin: j2:gpio29
pullup_resistor: 100000               # R3 = 100k (o padrão do Klipper é 4k7)
min_temp: 0
max_temp: 70                          # acima disso o Klipper desliga tudo

[gcode_button vm_sense_j2]            # monitor de 24 V: alto = 24 V presente
pin: j2:gpio1
press_gcode:
  G4 P0
release_gcode:
  M112                                # perdeu o 24 V com a máquina ligada: parada de emergência

# LED de status (opcional, sem peça na placa): o LED RGB WS2812 do próprio RP2040-Zero, no GP16.
# Aceso = o Klipper configurou este nó; apagado = nó reiniciou, sem firmware ou sem USB.
# Depois de um M112 o Klipper não roda macros: o LED fica na última cor (não dá para acender vermelho no erro).
# Repita em cada nó trocando o prefixo (j1:, j3:, z:) e o nome da seção.
#[neopixel status_j2]
#pin: j2:gpio16
#chain_count: 1
#color_order: RGB                     # no RP2040-Zero costuma ser RGB; vermelho e verde trocados: use GRB
#initial_RED: 0.0
#initial_GREEN: 0.0
#initial_BLUE: 0.15                   # azul fraco ao configurar (o LED é forte: 0,1–0,2 basta)
#
# Cores por evento, por macro. Exemplo: verde quando o Klipper fica pronto.
#[delayed_gcode status_pronto_j2]
#initial_duration: 1
#gcode:
#  SET_LED LED=status_j2 RED=0 GREEN=0.15 BLUE=0
#
# Em outras macros (homing, início do trabalho), por exemplo:
#   SET_LED LED=status_j2 RED=0.15 GREEN=0.08 BLUE=0     # laranja: fazendo homing

# -------------------------------------------------------------------------------------
#  Nó J1 — NEMA 23 + DM556 externo pelo J4 (soquete U4 vazio)
# -------------------------------------------------------------------------------------
[mcu j1]
serial: /dev/serial/by-id/usb-Klipper_rp2040_YYYYYYYYYYYYYYYY-if00   # AJUSTAR

[stepper_j1]                                                          # AJUSTAR nome
step_pin: !j1:gpio6                   # DM556 ânodo comum: o 74ACT245 afunda PUL- => pulso ativo baixo
dir_pin: j1:gpio7
enable_pin: j1:gpio8                  # GP8 alto = opto do ENA apagado = motor habilitado (SEM !)
step_pulse_duration: 0.000005         # DM556 pede >= 2,5 µs
microsteps: 16                        # AJUSTAR: igual às chaves SW5-SW8 do DM556
rotation_distance: 360                # AJUSTAR
gear_ratio: 6:1, 4:1                  # AJUSTAR
endstop_pin: !j1:gpio27               # AJUSTAR conforme NA/NF

[temperature_sensor motor_j1]
sensor_type: Generic 3950
sensor_pin: j1:gpio29
pullup_resistor: 100000
min_temp: 0
max_temp: 70

# Com dois motores na mesma placa (um no TMC2209, outro no DM556), o segundo NTC vai no J8:
#[temperature_sensor motor_2]
#sensor_type: Generic 3950
#sensor_pin: j1:gpio26                 # NTC2 no J8 (ADC0, pull-up 100k R15)
#pullup_resistor: 100000
#min_temp: 0
#max_temp: 70

[gcode_button vm_sense_j1]
pin: j1:gpio1
press_gcode:
  G4 P0
release_gcode:
  M112

# -------------------------------------------------------------------------------------
#  Acelerômetro para input shaping (opcional, por fio, sem conector na placa)
#  Livres: GP3, GP14, GP28. O ADXL345 do Klipper é só SPI (4 fios) e não cabe desde a v18;
#  use um I2C (MPU-6050/9250 ou LIS2DW) no GP3/GP14, 3V3 e GND soldados nos pinos do módulo.
# -------------------------------------------------------------------------------------
#[mpu9250]
#i2c_software_scl_pin: j2:gpio3
#i2c_software_sda_pin: j2:gpio14

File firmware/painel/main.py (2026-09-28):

# Boot do nó ScaraNode: drivers desabilitados e servidor do painel web (no.py).
# Ctrl+C (ou mpremote) para o servidor, solta o motor e cai no REPL; Ctrl+D reinicia.
from machine import Pin
Pin(0, Pin.OUT, value=1)   # EN do TMC2209 (ativo baixo)
Pin(8, Pin.OUT, value=0)   # ENA do DM556 (GP8 alto = habilitado): solto no boot
try:
    import no
    no.rodar()
except KeyboardInterrupt:
    pass

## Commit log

2026-09-25 docs(placa): publica ScaraNode v14 com manual completo
    Estrutura hardware/ production/ firmware/ docs/. Manual em Markdown + PDF
    com BOM ilustrado (foto, 3D e posição de cada peça), fabricação, montagem,
    pinagem, circuitos, Klipper e testes. Licença CERN-OHL-S-2.0.
    [BOM.csv, ScaraNode.kicad_pcb, scaranode.cfg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]
2026-09-25 docs(placa): corrige BOM e publica ScaraNode v15
    Conectores JST XH (peça real), 74ACT245 soldado direto sem soquete,
    borne 24 V verde e motor azul, resistores com faixas de cor por valor,
    pinagem desenhada do RP2040-Zero e TMC2209 no lugar de fotos erradas.
    [BOM.csv, ScaraNode.kicad_pcb, scaranode.cfg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]
2026-09-25 docs(placa): publica ScaraNode v16
    Placa 76 x 64 mm com furos M3 em retângulo de 69 x 57 mm e DXF mecânico,
    74ACT245 em soquete DIP-20, borne do motor KF128 azul, NTC separado dos
    fins de curso e LED de 5 mm.
    [BOM.csv, ScaraNode-mecanico.dxf, ScaraNode.kicad_pcb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]
2026-09-25 docs(placa): publica ScaraNode v17 com esquemático
    [BOM.csv, ScaraNode.kicad_pcb, ScaraNode.kicad_sch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]
2026-09-28 docs(placa): publica ScaraNode v18
    - Canais independentes: TMC2209 em GP4/GP5/GP0 e DM556 em GP6/GP7/GP8;
    uma placa pode mover dois motores ao mesmo tempo.
    - UART do TMC2209 no pino 4 do soquete (GP2 via JU); ate a v17 ia ao pino 5.
    - Sem o jumper ZM (MS1/MS2 fixos, endereco UART 3).
    - Segundo NTC (J8, GP26) e segunda saida de ventoinha (J9).
    - Nenhuma curva de trilha de 90 graus.
    - Fusivel de 2 A por placa (e 5 A por DM556) numa caixa de fusiveis de
    lamina, documentado no capitulo 6; avisos para nao queimar o driver no
    cfg e no capitulo 7.
    - Validada: 128 pinos, ERC e paridade 0, DRC de cobre sem erro.
    [BOM.csv, ScaraNode.kicad_pcb, ScaraNode.kicad_sch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]
2026-09-28 docs(firmware): exemplo de LED de status com o WS2812 do RP2040-Zero
    [scaranode.cfg]
2026-09-28 docs(placa): conectores plugaveis 2EDG e furos M3 esquadrados (v18)
    - J5 24 V: 2EDGRC 90 graus + plugue 2EDGK, entrando pela borda de cima.
    - J6 motor: 2EDGVC vertical + plugue 2EDGK, fio saindo para a direita.
    - Os quatro furos M3 nos cantos (retangulo de 69 x 57 mm); DXF atualizado.
    - C10 a 1,4 mm do J5. Validada: 128 pinos, DRC de cobre sem erro.
    [BOM.csv, ScaraNode-mecanico.dxf, ScaraNode.kicad_pcb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]
2026-09-28 docs(producao): pacote para o operador da CNC (v18)
    production/cnc/: um arquivo por ferramenta, com a operacao e a ferramenta no
    nome, e um PDF de instrucoes; zip pronto para enviar.
    [ScaraNode-v18_1_ISOLACAO_fresa-ate-0.6mm.gbl, ScaraNode-v18_2_FURO_broca-1.0mm_120-furos.drl, ScaraNode-v18_3_FURO_broca-1.6mm_8-furos.drl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]
2026-09-28 firmware(painel): boas-vindas, link do GitHub e aba Firmware com download
    - tela de boas-vindas enquanto não há placa conectada (MicroPython,
    firmware, conectar), com Fechar e o botão Ajuda para reabrir
    - link do repositório no topo
    - aba Firmware própria: gravar a versão do site, baixar no.py/main.py/placa.py
    para editar e gravar os arquivos editados do computador
2026-09-29 firmware(painel): 1.12 le o NTC pelo Pin e mostra o NTC2 da v18
    ADC(3) no MicroPython 1.29 deixava o pull-down do GP29 ligado e o NTC
    marcava ~60 C no ar. NTC2 (GP26) com R25/beta proprios no painel.
2026-09-29 docs(historico): NTC2 e fins de curso da v18 validados
2026-09-30 firmware(painel): 1.13 com modo dois, trajetória e config na placa; página do robô
    - no.py: modo "dois" na v18 (TMC e DM556 juntos, posição por canal, "k" nos
    comandos, fim de curso com dono k1/k2); trajetória sincronizada em PIO1
    SM1/SM2 + DMA em anel (tjini/tj), com sentinela e contagem exata no corte;
    config.json (comando salva) lido na partida; uid e boot no info.
    - robo.html: várias placas, eixos J1/J2/Z salvos nas placas, referência por
    fim de curso ou manual, cinemática SCARA, desenho de formas e SVG com
    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
2026-09-30 firmware(painel): robô atualiza o firmware de cada placa pela revisão dela
2026-09-30 firmware(painel): 1.14 corrige a 1.13 que não iniciava no MicroPython
    - int.bit_length() não existe no MicroPython: o no.py 1.13 quebrava ao importar
    e a placa não respondia depois de gravar.
    - no RP2040 o abort do DMA zera o TRANS_COUNT: a contagem de palavras da
    trajetória agora é lida antes do abort (posição final estava errada).
    - sentinela da trajetória fica num laço (jmp) mesmo se o irq for limpo.
    Conferido na v18 em bancada (drivers desabilitados): pulsos contados por outra
    SM batem com a posição no fim e em 4 paradas no meio; config.json volta na partida.
    [no.py]
2026-09-30 firmware(painel): link do robô para o painel aponta para index.html (funciona aberto do disco)
2026-10-05 chore(painel): remove a v17 e o modo Ambos das páginas
    Não há mais placas até a v17. Preferência salva com v17/ambos cai para v18/TMC.
    O no.py mantém a pinagem da v17.
2026-10-05 fix(painel): 1.15 lê a linha da USB num buffer fixo
    A linha era montada caractere a caractere numa lista; num bloco tj (~1,3 kB)
    a lista dobrava e pedia 4-8 kB contíguos. Com o heap fragmentado vinha
    MemoryError no laço principal a cada caractere: trajetória cortada no meio
    do desenho e a placa sem responder por segundos. Agora a linha vai para um
    bytearray alocado uma vez e o json.loads lê direto dele.
    Teste de bancada (placa na USB) fragmenta o heap sem bloco de 8 kB livre.
    [no.py]
